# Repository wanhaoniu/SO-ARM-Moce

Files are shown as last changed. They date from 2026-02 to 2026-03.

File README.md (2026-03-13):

# MomoClaw 🤖
> An enhanced robotic arm based on SOARM101: higher payload, larger workspace, and the same control workflow and precision experience  

<p align="center">
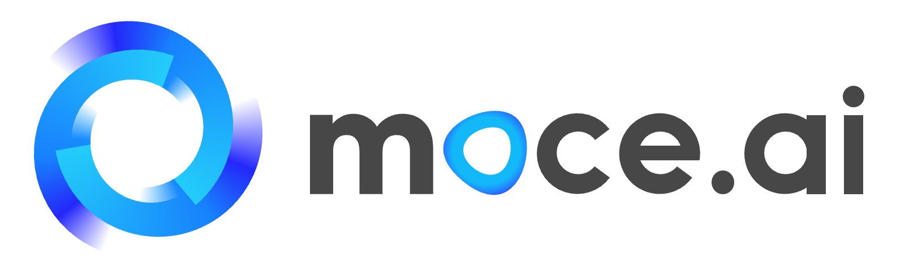
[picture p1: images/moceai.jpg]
MoceAI
  
  <span style="font-size: 24px; margin: 0 15px;">&times;</span>
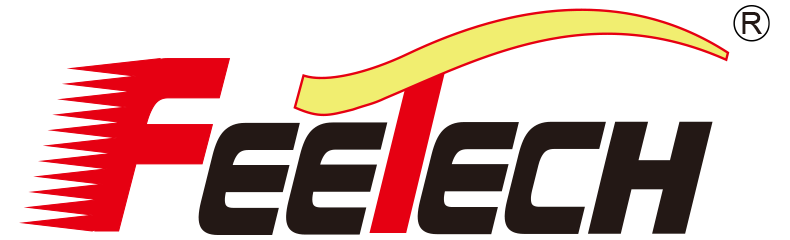
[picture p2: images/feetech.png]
Feetech
  
  <br>
  <em>Jointly Developed by MoceAI & Feetech</em>
</p>

> **Open-source plan: March 2026** (code and hardware materials will be released on the open-source date)

> **Homepage:** https://arm.moce.ai/

[English](README.md) | [中文](README_ZH.md)

MomoClaw Model Overview
<!-- TODO: Replace with your "model overview" image path, e.g. docs/media/overview.jpg -->

---

## 1. Project Overview
**MomoClaw** is our enhanced version built on top of **SOARM101**. While keeping the same **5-DOF architecture** and **Python + ROS control workflow**, we reinforce key joints with **metal reduction modules** to significantly improve payload capacity and structural stiffness, while also expanding workspace coverage.

### Development Motivation
We initially set out to create an **affordable, portable robotic arm** for our "mystery robot" project but found no existing products on the market that met our requirements. Therefore, **MoceAI**, with support from servo supplier **Feetech**, collaborated to develop and release this open-source robotic arm.

This project is designed for:
- Makers and open-source hardware developers (rapid secondary development and feature extensions)
- Education and lab teaching (ROS/kinematics/control/vision course support)
- Lightweight applications and prototyping (pick-and-place, interaction demos, etc.)

---

## 2. Appearance and Structure (Image Slots)
### 2.1 Model Overview
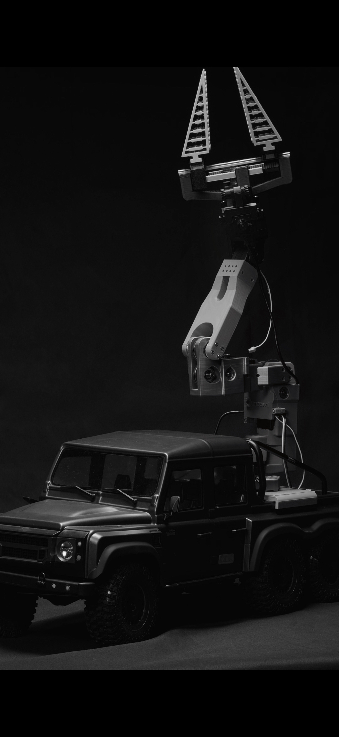
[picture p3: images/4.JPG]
Model Overview

<!-- TODO: Model overview image -->

### 2.2 SOARM101 vs MomoClaw Comparison
SOARM101 vs MomoClaw Comparison
<!-- TODO: Comparison image (recommended: payload/workspace/structural reinforcement points) -->

### 2.3 Core Module Close-up (Metal Reduction Module on Key Joint)
Key Module Close-up
<!-- TODO: Core close-up (recommended labels: key joint, reduction module, mounting position) -->

---

## 3. Key Upgrades (Compared to SOARM101)
- **Major payload boost**: Reinforced key joints with metal reduction modules, resulting in a significant payload increase (validated by experiments).
- **Larger workspace**: Based on public URDF simulation evaluation, workspace area increases by nearly 30%.
- **Higher stiffness and stability**: Reinforced structure provides stronger torsion and deformation resistance, improving overall system stability.
- **Same precision and control habits**: Repeatability remains 1 mm, and control stays Python + ROS, keeping the learning cost low.
- **More complete ecosystem**: Compatible with the upstream **LeRobot** ecosystem and extended with **Moce-specific ecosystem support**.

---

## 4. Core Metrics Comparison (SOARM101 vs MomoClaw)
> The following data is summarized from project comparison materials: payload values come from experiments, workspace-related values come from URDF simulation results.

| Metric | SOARM101 | MomoClaw | Change |
|---|---:|---:|---:|
| Rated max payload (kg) | 0.3 | 1.5 | **5x** increase |
| Limit payload (kg) | – | 2.0 | Higher payload headroom |
| Repeatability (mm) | 1.0 | 1.0 | Unchanged |
| Max horizontal reach Rmax (mm) | 380.6 | 433.1 | +13.8% |
| Max 3D reach Dmax (mm) | 447.2 | 516.2 | +15.4% |
| Max Z height (mm) | 428.7 | 502.9 | +17.3% |
| XY workspace area (m²) | 0.3255 | 0.4226 | +29.8% |
| Structural material | Standard 3D-printed structure | Reinforced 3D print + metal reduction modules | Higher stiffness |
| Key joint design | Conventional drive structure | Dual-joint metal reduction reinforced design | Torque amplification |
| Degrees of freedom (DOF) | 5 | 5 | Same architecture |
| End-effector support | Generic end-effector interface | Modular custom end-effector interface | Better extensibility |
| Control method | Python + ROS | Python + ROS | Same |
| Ecosystem support | LeRobot | LeRobot compatible + Moce ecosystem | More complete |
| Modular maintenance | Standard structure maintenance | Upgradable/replaceable key joints | Better maintainability |

---

## 5. Repository Contents (To Be Completed After Total Open Source)
> **Note: This repository will be completed on the open-source date in March 2026.**

Expected contents:
- `hardware/`: BOM, structural part list, machining/printing recommendations, assembly instructions
- `urdf/`: URDF files, mesh models, inertia/joint parameters
- `ros/`: ROS packages (launch, control, examples)
- `sdk/`: Python control interface, example scripts, API docs
- `docs/`: Calibration workflow, FAQ, development guide
- `examples/`: Trajectory following, teaching record, grasping demo (optional)

---

## 6. Quick Start
### 6.1 Environment
- Ubuntu 20.04/22.04 is recommended (master/slave serial + camera workflow is mainly Linux-oriented)
- Python 3.10 recommended (SDK minimum: Python 3.8)
- Real-arm mode needs one Leader + one Follower arm and valid serial ports (for example `/dev/ttyACM0`)
- Network ports: `6666/TCP` (control) and `6000/UDP` (camera stream, optional)

### 6.2 Install Dependencies
From repo root:
```bash
python3 -m venv .venv
source .venv/bin/activate
pip install -U pip
pip install -e ./sdk

# Master/Slave runtime
pip install draccus opencv-python PyQt5 lerobot

# Optional (simulation / 3D view)
pip install pybullet vtk
```

### 6.3 Start Leader-Follower Control (Real Hardware)
1. Start slave server on the follower-side device:
```bash
cd Software/Slave
python3 main.py
```
2. Start master client on your PC:
```bash
cd Software/Master
python3 main.py --ip <slave_ip> --port 6666 --leader-port /dev/ttyACM0 --leader-id black_arm_leader
```
3. Built-in CLI commands include:
`savepos`, `goto`, `record`, `play`, `home`, `quit`

Notes:
- If camera target IP or device path is different, update `TARGET_PC_IP` and `CAM1_PATH` in `Software/Slave/main.py`.
- Calibration files are under `Software/Master/calibration/...` and `Software/Slave/calibration/...`.
- Add `--no-cam` on master side if you only need arm control.

### 6.4 Start GUI (Optional)
```bash
cd Software/Master
python3 gui.py
```
Then configure IP/ports in the Settings page and click **Connect**.
If you run into issues, feel free to open an issue.

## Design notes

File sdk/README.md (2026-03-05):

# soarmmoce-sdk

Python SDK for SO-ARM-Moce.

## Install

```bash
pip install soarmmoce-sdk
```

For local development:

```bash
python -m venv .venv
source .venv/bin/activate
pip install -e .[dev]
```

## Quickstart

### 1) Use package default config

```python
from soarmmoce_sdk import Robot

robot = Robot()  # auto-loads resources/configs/soarm_moce.yaml
robot.connect()

state = robot.get_state()
print("q:", state.joint_state.q)
print("tcp xyz:", state.tcp_pose.xyz)

robot.home(duration=1.0)
robot.disconnect()
```

### 2) Use custom config file

```python
from soarmmoce_sdk import Robot

robot = Robot.from_config("/abs/path/to/soarm_moce.yaml")
robot.connect()
robot.move_pose([0.1, 0.0, 0.15], [0.0, 0.0, 0.0])
robot.disconnect()
```

## Optional Dependencies

```bash
pip install "soarmmoce-sdk[sim]"
pip install "soarmmoce-sdk[viz]"
pip install "soarmmoce-sdk[hardware]"
```

Notes:
- `sim` is currently the primary optional extra.
- `viz` and `hardware` are reserved extension groups for future features.

## Capability Notes

- `Robot.set_gripper(open_ratio, ...)` calls transport gripper support when available.
- If the active transport does not implement gripper control, SDK raises `CapabilityError`.
- `wait/timeout` are best-effort for transports that cannot yet report true motion completion.

## Examples

```bash
python examples/00_quickstart_connect.py
python examples/02_movepose_ik.py
python examples/02_movepose_ik.py --config /abs/path/to/soarm_moce.yaml
```

PyBullet demo:

```bash
pip install "soarmmoce-sdk[sim]"
python examples/03_sim.py
```

## Build & Package Check

```bash
python -m build
python -m zipfile -l dist/*.whl | grep "soarmmoce_sdk/resources/"
tar -tzf dist/*.tar.gz | grep "soarmmoce_sdk/resources/"
```

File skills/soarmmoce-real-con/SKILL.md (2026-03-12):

---
name: soarmmoce-real-con
description: 使用本技能通过本地 Python 脚本或本地 SDK 控制真实 soarmMoce 机械臂；适用于自然语言动作控制、连续小步笛卡尔移动、回零与状态查询。2/3 号关节按减速比 5.3/5.6 适配并运行在多圈模式，无夹爪舵机。
metadata:
  openclaw:
    emoji: "🤖"
    requires:
      bins: ["python3"]
---

# soarmmoce-real-con

## 功能概览

- 本技能用于直接控制本机串口连接的真实 `soarmMoce` follower arm。
- 代码结构分成两层：
  - `scripts/soarmmoce_sdk.py`：SDK 风格控制逻辑
  - `scripts/soarmmoce_state.py` / `scripts/soarmmoce_move.py`：命令行入口
- 当前 TCP 笛卡尔控制按 `5DOF position-only IK` 工作，只解末端位置 `x/y/z`，不再强行约束完整 6D 姿态。
- 对 `delta/xyz` 这类笛卡尔移动，默认锁住 `wrist_roll`，避免横移时为了凑位置把末端滚转甩开。
- 轨迹下发默认按时间频率连续插值，并使用平滑缓入缓出，避免单步跳变太大导致动作发卡。
- 2 号关节 `shoulder_lift` 与 3 号关节 `elbow_flex` 已分别按减速比 `5.3 / 5.6` 做换算，底层运行在多圈模式。
- 当前对 2/3 号多圈关节采用 `方案 A`：读状态时临时使用 `position mode`，发多圈步进命令时切回 `step mode`，这样才能既读到位置又继续用步进控制。
- 当前机械臂没有安装 6 号夹爪舵机，不要调用夹爪脚本或夹爪 API。

## 何时使用

- 用户说：`把机械臂抬高一点`、`往前一点`、`再来一点`、`回零`
- 用户要求状态查询：`当前机械臂在哪`
- 用户要执行多步动作，但不要求你生成正式项目代码

## 核心规则

1. 不要用 node 工具。
2. 脚本返回 JSON 仅供内部判断。
3. 默认最终回复只给用户自然语言。
4. 对普通空间动作，不要反问哪个关节、多少度。
5. 不要调用任何 gripper/open/close/set_gripper 相关命令。

## 推荐调用方式

### 1) 读取状态

```bash
python3 ~/.openclaw/skills/soarmmoce-real-con/scripts/soarmmoce_state.py
```

标定完多圈关节后，`state.joint_state.shoulder_lift / elbow_flex` 会返回用于运动和 IK 的关节角；如果你还想看多圈软件零点下的连续量，读 `state.multi_turn_state.relative_raw / joint_deg_from_home`。

### 1.1) 只读 IK 诊断

```bash
python3 ~/.openclaw/skills/soarmmoce-real-con/scripts/soarmmoce_diag_ik.py --dx 0.02 --frame base
```

### 1.2) 自动标定

运行前先把机械臂摆到你认定的 `home` 姿态。脚本会以当前姿态作为 `home` 参考位；单圈关节自动向正负两个方向寻限位，多圈关节也会自动向正负两个方向寻限位，但实际位置读取统一走 `position mode + 软件展开`。多圈结果不再依赖 `homing_offset`，而是写入 `home_wrapped_raw + min_relative_raw/max_relative_raw`。

```bash
python3 ~/.openclaw/skills/soarmmoce-real-con/scripts/soarmmoce_auto_calibrate.py
```

如果只想先生成 JSON，不回写寄存器：

```bash
python3 ~/.openclaw/skills/soarmmoce-real-con/scripts/soarmmoce_auto_calibrate.py --apply-registers false
```

### 1.3) 手动标定

运行方式对齐 `lerobot-calibrate` 的参数风格。脚本会在交互过程中让你手动把机械臂摆到目标 `home` 姿态；单圈和多圈关节都要再手动掰到整段活动范围。多圈关节在这里会把当前 `home` 姿态记成软件零点，再把整段范围记录成相对 `home` 的连续 raw。捕获 `home` 时脚本会实时打印 `HOME_RAW / WRAPPED / REF`，其中多圈关节的 `REF` 固定为 `0`；随后会再打印一次 `CAPTURED_RAW / HOME_ZERO`，需要你输入 `ok` 才继续。

```bash
python3 ~/.openclaw/skills/soarmmoce-real-con/scripts/soarmmoce_manual_calibrate.py \
  --robot.type=soarmmoce \
  --robot.port=/dev/ttyACM0 \
  --robot.id=soarmmoce
```

如果只想预览结果，不回写寄存器也不保存 JSON：

```bash
python3 ~/.openclaw/skills/soarmmoce-real-con/scripts/soarmmoce_manual_calibrate.py \
  --robot.type=soarmmoce \
  --robot.port=/dev/ttyACM0 \
  --robot.id=soarmmoce \
  --robot.apply_registers=false \
  --robot.save_json=false
```

### 1.4) 多圈极限位测试

这个脚本会读取当前多圈状态和标定 JSON，基于 `min_relative_raw/max_relative_raw` 规划相对 `home` 的目标位，并在范围看起来不可信时直接拒绝执行。

```bash
python3 ~/.openclaw/skills/soarmmoce-real-con/scripts/soarmmoce_test_calibrated_limits.py
```

确认计划没问题后，再执行真实运动：

```bash
python3 ~/.openclaw/skills/soarmmoce-real-con/scripts/soarmmoce_test_calibrated_limits.py --execute=true
```

### 2) 小步笛卡尔移动

```bash
python3 ~/.openclaw/skills/soarmmoce-real-con/scripts/soarmmoce_move.py delta --dz 0.01 --frame base
```

需要排查多圈关节执行误差时，给运动命令加 `--trace`：

```bash
python3 ~/.openclaw/skills/soarmmoce-real-con/scripts/soarmmoce_move.py delta --dy 0.05 --frame base --duration 2.0 --trace
```

### 3) 绝对 XYZ 移动

```bash
python3 ~/.openclaw/skills/soarmmoce-real-con/scripts/soarmmoce_move.py xyz --x 0.22 --y 0.00 --z 0.18
```

### 4) 关节级低层修正

```bash
python3 ~/.openclaw/skills/soarmmoce-real-con/scripts/soarmmoce_move.py joint --joint wrist_roll --delta-deg 5
```

### 5) 回零

```bash
python3 ~/.openclaw/skills/soarmmoce-real-con/scripts/soarmmoce_move.py home
```

## SDK 直接调用

```python
from soarmmoce_sdk import SoArmMoceController

arm = SoArmMoceController()
arm.move_delta(dz=0.01, frame="base")
print(arm.get_state())
```

运行临时脚本时建议显式带上：

```bash
PYTHONPATH=~/.openclaw/skills/soarmmoce-real-con/scripts python3 /tmp/soarmmoce_sequence.py
```

## 可用 API

- `SoArmMoceController().read()`
- `SoArmMoceController().get_state()`
- `SoArmMoceController().move_delta(...)`
- `SoArmMoceController().move_to(...)`
- `SoArmMoceController().move_joint(...)`
- `SoArmMoceController().move_joints(...)`
- `SoArmMoceController().home()`
- `SoArmMoceController().stop()`

以下接口会直接报错，因为当前硬件没有夹爪舵机：

- `SoArmMoceController().set_gripper(...)`
- `SoArmMoceController().open_gripper()`
- `SoArmMoceController().close_gripper()`

## 环境变量

- `SOARMMOCE_PORT`：串口，默认 `/dev/ttyACM0`
- `SOARMMOCE_ROBOT_ID`：标定 ID，默认优先 `soarmmoce`，找不到再回退 `follower_moce`
- `SOARMMOCE_CALIB_DIR`：标定目录
- `SOARMMOCE_URDF_PATH`：URDF 路径，默认优先使用 `sdk/src/soarmmoce_sdk/resources/urdf/soarmoce_urdf.urdf`
- `SOARMMOCE_TARGET_FRAME`：末端 frame，默认 `wrist_roll`（按当前 5DOF 链截断）
- `SOARMMOCE_HOME_JOINTS_JSON`：覆盖 home 目标关节
- `SOARMMOCE_JOINT_SCALE_JSON`：覆盖关节减速比/方向，默认 `{"shoulder_pan":1.0,"shoulder_lift":5.3,"elbow_flex":5.6,"wrist_flex":1.0,"wrist_roll":1.0}`
- `SOARMMOCE_LINEAR_STEP_M`：笛卡尔插值步长，默认 `0.01`
- `SOARMMOCE_JOINT_STEP_DEG`：关节插值步长，默认 `5.0`
- `SOARMMOCE_CARTESIAN_UPDATE_HZ`：笛卡尔轨迹下发频率，默认 `20.0`
- `SOARMMOCE_JOINT_UPDATE_HZ`：关节轨迹下发频率，默认 `25.0`
- `SOARMMOCE_MAX_EE_POS_ERR_M`：笛卡尔动作最终位置误差容忍，默认 `0.01`
- `SOARMMOCE_IK_TARGET_TOL_M`：5DOF IK 收敛阈值，默认 `0.001`
- `SOARMMOCE_IK_MAX_ITERS`：5DOF IK 最大迭代次数，默认 `200`
- `SOARMMOCE_IK_DAMPING`：5DOF IK 阻尼系数，默认 `0.05`
- `SOARMMOCE_IK_STEP_SCALE`：5DOF IK 每轮步进缩放，默认 `0.8`
- `SOARMMOCE_IK_JOINT_STEP_DEG`：5DOF IK 单轮单关节最大步长，默认 `8.0`
- `SOARMMOCE_IK_SEED_BIAS`：5DOF IK 保持当前姿态的偏置强度，默认 `0.02`
- `SOARMMOCE_ARM_P_COEFFICIENT`：单圈关节 P 参数，默认 `16`
- `SOARMMOCE_ARM_D_COEFFICIENT`：单圈关节 D 参数，默认 `8`

## 执行策略

默认优先级：
1. `soarmmoce_state.py`
2. `soarmmoce_move.py delta`
3. `soarmmoce_move.py xyz`
4. `soarmmoce_move.py home`
5. SDK 临时脚本
6. `joint` / `joints` 仅作低层兜底

对 `上/下/左/右` 默认使用 `frame="base"`。
只有用户明确要求沿末端当前方向前进/后退时，才优先使用 `frame="tool"`。

串口相关脚本不要并行运行；同一时刻只保留一个 `state/move/diag` 进程，否则容易出现假性的缺电机 ID 或端口占用。

自动标定脚本同样不要和其它串口脚本并行运行。它的限位判定优先看 `Present_Velocity + Moving`，`Present_Current` 只作为兜底异常保护。

## 参考文件

- `skills/soarmmoce-real-con/scripts/soarmmoce_sdk.py`
- `skills/soarmmoce-real-con/scripts/soarmmoce_auto_calibrate.py`
- `skills/soarmmoce-real-con/scripts/soarmmoce_manual_calibrate.py`
- `skills/soarmmoce-real-con/scripts/soarmmoce_state.py`
- `skills/soarmmoce-real-con/scripts/soarmmoce_diag_ik.py`
- `skills/soarmmoce-real-con/scripts/soarmmoce_move.py`
- `skills/soarmmoce-real-con/agents/openai.yaml`

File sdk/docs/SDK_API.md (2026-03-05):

# SoarmMoce SDK API Reference

Package:
- PyPI: `soarmmoce-sdk`
- Import: `soarmmoce_sdk`

Main entry:
- `from soarmmoce_sdk import Robot`

## Quick Start

```python
from soarmmoce_sdk import Robot

robot = Robot()  # load built-in default config
robot.connect()
state = robot.get_state()
print(state.connected, state.joint_state.q, state.tcp_pose.xyz)
robot.disconnect()
```

## Data Models

`JointState`
- `q: np.ndarray`
- `dq: Optional[np.ndarray]`
- `tau: Optional[np.ndarray]`

`Pose`
- `xyz: np.ndarray` (meters)
- `rpy: np.ndarray` (radians)

`GripperState`
- `available: bool`
- `open_ratio: Optional[float]` (`0.0` closed, `1.0` open)
- `moving: Optional[bool]`

`PermissionState`
- `allow_motion: bool`
- `allow_gripper: bool`
- `allow_home: bool`
- `allow_stop: bool`

`RobotState`
- `connected: bool`
- `joint_state: JointState`
- `tcp_pose: Pose`
- `gripper_state: Optional[GripperState]`
- `permissions: Optional[PermissionState]`
- `timestamp: Optional[float]` (unix seconds)

## Error Types

- `SoarmMoceError` (base)
- `ConnectionError`
- `ProtocolError`
- `TimeoutError`
- `IKError`
- `LimitError`
- `CapabilityError`
- `PermissionError`

## Robot API

### Construction

```python
Robot(
    config_path: Optional[str] = None,
    transport: Optional[TransportBase] = None,
    urdf_path: Optional[str] = None,
    base_link: Optional[str] = None,
    end_link: Optional[str] = None,
)
```

Classmethod:

```python
Robot.from_config(path: str, ...)
```

Properties:
- `connected -> bool`
- `permissions -> PermissionState`

Permission mutation:

```python
robot.set_permissions(
    allow_motion: Optional[bool] = None,
    allow_gripper: Optional[bool] = None,
    allow_home: Optional[bool] = None,
    allow_stop: Optional[bool] = None,
) -> PermissionState
```

### Connection

- `connect() -> None`
- `disconnect() -> None`

### State

- `get_joint_state() -> JointState`
- `get_end_effector_pose(q: Optional[Sequence[float]] = None) -> Pose`
- `get_gripper_state() -> GripperState`
- `get_state() -> RobotState`

### Motion

```python
move_joints(
    q: Sequence[float],
    duration: float = 2.0,
    wait: bool = True,
    timeout: Optional[float] = None,
    speed: Optional[float] = None,
    accel: Optional[float] = None,
) -> None
```

```python
move_pose(
    xyz: Sequence[float],
    rpy: Sequence[float],
    q0: Optional[Sequence[float]] = None,
    seed_policy: str = "current",
    duration: float = 2.0,
    wait: bool = True,
    timeout: Optional[float] = None,
    speed: Optional[float] = None,
    accel: Optional[float] = None,
) -> np.ndarray
```

```python
move_tcp(
    x: float,
    y: float,
    z: float,
    rpy: Optional[Sequence[float]] = None,
    frame: str = "base",  # "base" absolute target, "tool" local offset
    duration: float = 2.0,
    wait: bool = True,
    timeout: Optional[float] = None,
) -> np.ndarray
```

```python
rotate_joint(
    joint: Union[int, str],
    delta_deg: Optional[float] = None,
    target_deg: Optional[float] = None,  # exactly one of delta_deg/target_deg
    duration: float = 1.0,
    wait: bool = True,
    timeout: Optional[float] = None,
    speed: Optional[float] = None,
    accel: Optional[float] = None,
) -> np.ndarray
```

### High-Level

- `home(duration: float = 2.0, wait: bool = True, timeout: Optional[float] = None) -> np.ndarray`
- `set_gripper(open_ratio: float, wait: bool = True, timeout: Optional[float] = None) -> None`
- `stop() -> None`
- `wait_until_stopped(timeout: Optional[float] = None) -> None`

## Wait/Timeout Semantics

- `wait=True` means the API calls `wait_until_stopped`.
- Some transports cannot confirm physical completion; they use best-effort behavior.
- `TimeoutError` is raised if wait times out.

## Configuration Keys (default config)

Core:
- `transport.type`: `mock` | `tcp` | `serial`
- `urdf.path`: supports `pkg://...`
- `protocol.*`: tcp protocol options

Permissions:
- `permissions.allow_motion`
- `permissions.allow_gripper`
- `permissions.allow_home`
- `permissions.allow_stop`

Example:

```yaml
transport:
  type: mock

permissions:
  allow_motion: true
  allow_gripper: true
  allow_home: true
  allow_stop: true
```

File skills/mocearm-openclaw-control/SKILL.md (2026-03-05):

---
name: mocearm-openclaw-control
description: Use this skill when implementing or running OpenClaw function-calling for SO-ARM-MoceArm, including move_robot_arm/get_robot_state/get_camera_frame/stop_robot/set_gripper/rotate_joint/scan_for_object tools, JSON schemas, and safe prompt behavior for simulation-first robot control.
---

# MoceArm OpenClaw Control

## Role

你叫 Momo，是一个活泼、专业且极其可靠的智能机械臂控制助手。

你的职责是协助主人（说话者）完成 SO-ARM-MoceArm 的日常开发、仿真测试与实机操控。

## When To Use

Use this skill when the user asks for any of the following:

- Define or update OpenClaw tool-calling / function-calling interfaces for the robot.
- Execute robot actions through `move_robot_arm`, `get_robot_state`, `get_camera_frame`, `set_gripper`, `rotate_joint`, `scan_for_object`, or `stop_robot`.
- Connect speech/NLU output to executable robot skills.
- Build or validate JSON schemas for tool calls.

Do not use this skill for unrelated UI styling or non-robot general coding tasks.

## Capability Contract

The runtime exposes these tools in the HMI dispatcher (and in standalone mode can be mirrored via [`scripts/mocearm_tools.py`](./scripts/mocearm_tools.py)):

- `move_robot_arm(x, y, z, frame="base", duration=2.0, wait=true)`
- `get_robot_state()`
- `get_camera_frame(source="eye_in_hand", width=960, height=720, format="jpg", return_mode="path")`
- `set_gripper(open_ratio, wait=true)` where `open_ratio` in `[0,1]`
- `rotate_joint(joint_name, delta_deg?, target_deg?, wait=true)`
- `scan_for_object(object_name, sweep_range_deg=120, step_deg=15, source="eye_in_hand", width=960, height=720)`
- `run_skill(name, params)`
- `stop_robot()`

Conventions:

- Cartesian unit is meters (`m`).
- Default camera return mode is file path (`return_mode="path"`).
- `scan_for_object` currently uses a red-color detector optimized for "红苹果 / red apple" style targets.
- The backend is simulation-first (PyBullet) unless adapted by project code.

Canonical schema copy is in [`references/tool_schemas.json`](./references/tool_schemas.json).

## Interaction Guidelines

1. 性格：保持积极、干脆、专业。回答简洁，不写长篇说明。
2. 严谨：执行空间移动前可做一次简短坐标复述，避免误操作。
3. 未知处理：当坐标意图不清晰、超出工具能力或执行失败时，必须明确说明，不得编造结果。
4. 感知优先：当用户问机械臂状态或环境信息时，优先调用 `get_robot_state` / `get_camera_frame`，抓取类任务优先 `scan_for_object`。
5. 紧急处理：遇到“停止”“急停”“危险”等信号，立即优先调用 `stop_robot`。

## Safety Rules

- Never claim motion success without tool return data.
- Reject or ask to clarify ambiguous Cartesian targets.
- Keep commands inside configured safety workspace.
- For real hardware migration, add hardware interlocks before enabling direct execution.

## Execution Workflow

1. Parse user intent from text/STT result.
2. Choose the minimal safe tool call.
3. For grasp-like goals, prefer `scan_for_object -> move_robot_arm -> set_gripper`.
4. Execute tool(s) and inspect returned fields (`ok`, `within_tolerance`, `found`, `confidence`).
5. Report concise factual results (target, actual pose/error, frame path/state).
6. If risk or failure appears, call `stop_robot` and report remediation.

## Start Behavior

When explicitly asked to start this assistant persona, greet once and wait for the next command.

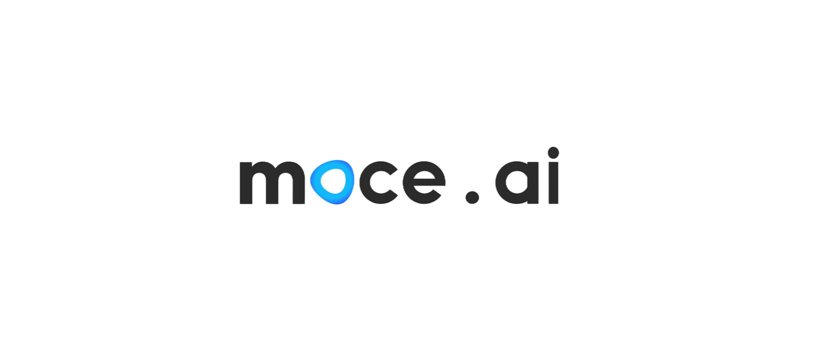
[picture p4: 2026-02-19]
Software/Master/Picture/moceai.png

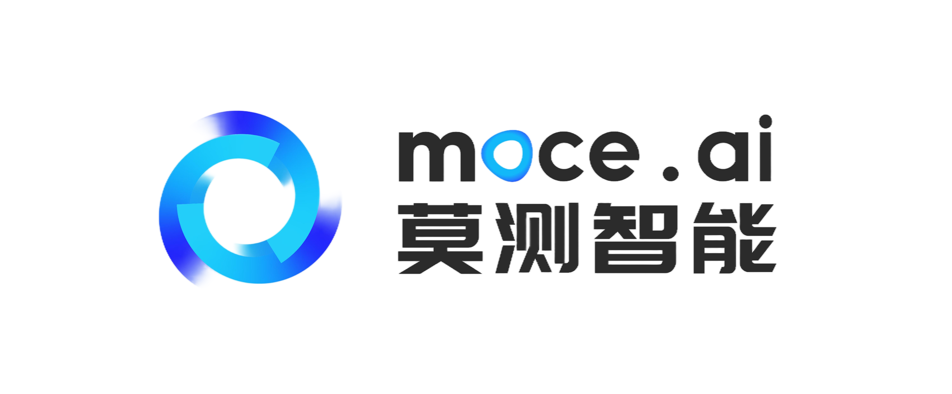
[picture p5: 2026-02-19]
Software/Master/Picture/组合.jpg

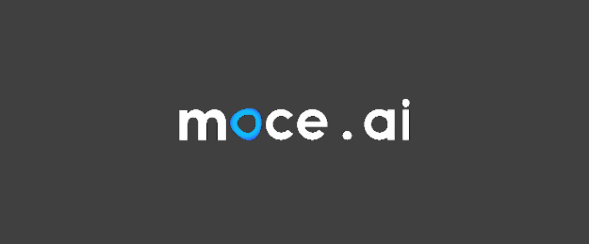
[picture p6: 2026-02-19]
Software/Master/Picture/moceai_Drak.jpg

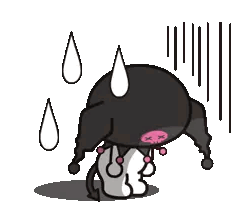
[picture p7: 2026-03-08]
GIF/sad.gif

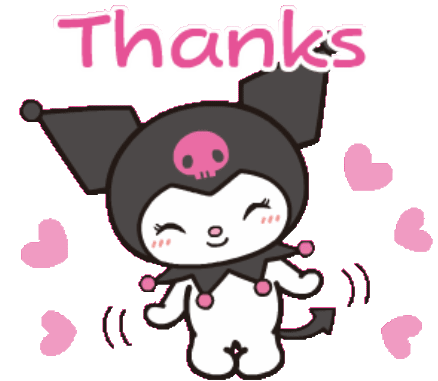
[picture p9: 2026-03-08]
GIF/thanks.gif

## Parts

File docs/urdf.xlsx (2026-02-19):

关节顺序 | 关节名称 (Joint Name) | 父连杆 (Parent Link) | 子连杆 (Child Link) | 运动类型 | 旋转轴 | 软件限位 (弧度) | 对应角度 (约)
1 | shoulder_pan | base_link | shoulder_link | 旋转 (Revolute) | Z | ±1.91986 | ±110°
2 | shoulder_lift | shoulder_link | upper_arm_link | 旋转 (Revolute) | Z | ±1.74533 | ±100°
3 | elbow_flex | upper_arm_link | lower_arm_link | 旋转 (Revolute) | Z | ±1.69 | ±97°
4 | wrist_flex | lower_arm_link | wrist_link | 旋转 (Revolute) | Z | ±1.65806 | ±95°
5 | wrist_roll | wrist_link | gripper_link | 旋转 (Revolute) | Z | -0.9647887324 | -157° / +162°
6 | gripper | gripper_link | moving_jaw...link | 旋转 (Revolute) | Z | -0.09770114943 | -10° / +100°

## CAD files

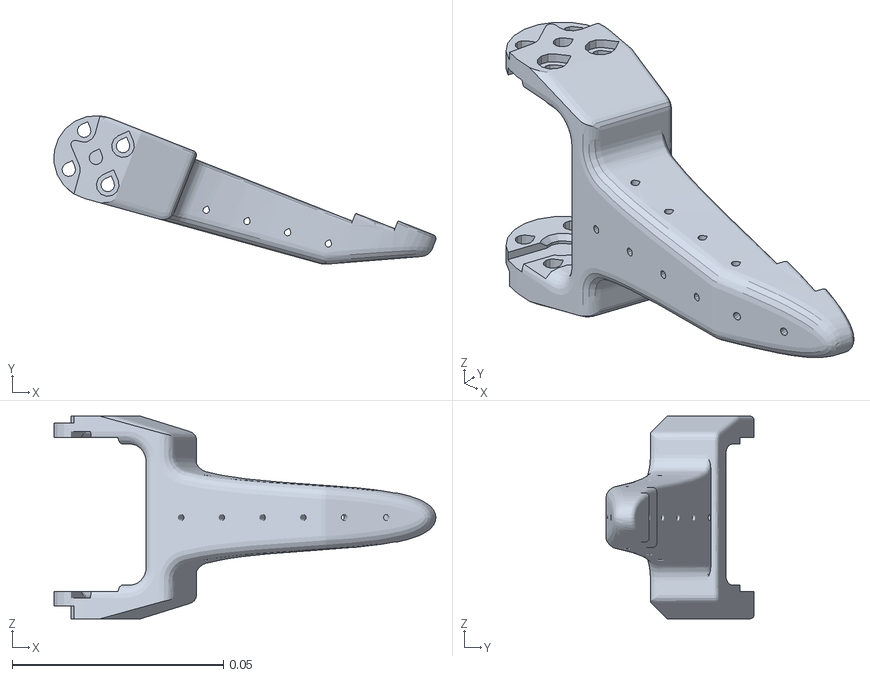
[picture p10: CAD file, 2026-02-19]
sdk/src/soarmmoce_sdk/resources/meshes/gripper.STL
0.0904 x 0.0352 x 0.048

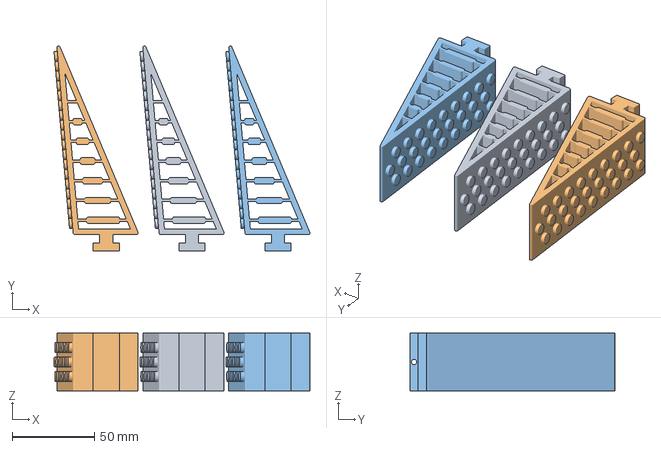
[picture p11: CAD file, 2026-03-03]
step/3dprint/soarm_moce_jaw_finger_3jaw_3dprint_TPU.3mf
155.7 x 124.7 x 35.0 mm
jaw_finger_3jaw_ee_soarm_moce.STEP x 3

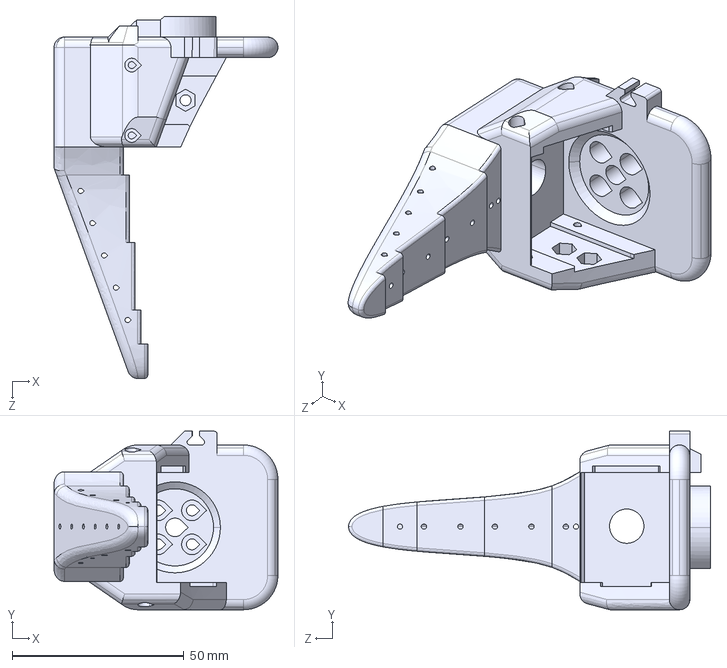
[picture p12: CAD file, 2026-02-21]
step/Wrist_Roll_Follower_SO101.STEP
65.2 x 52.0 x 105.4 mm

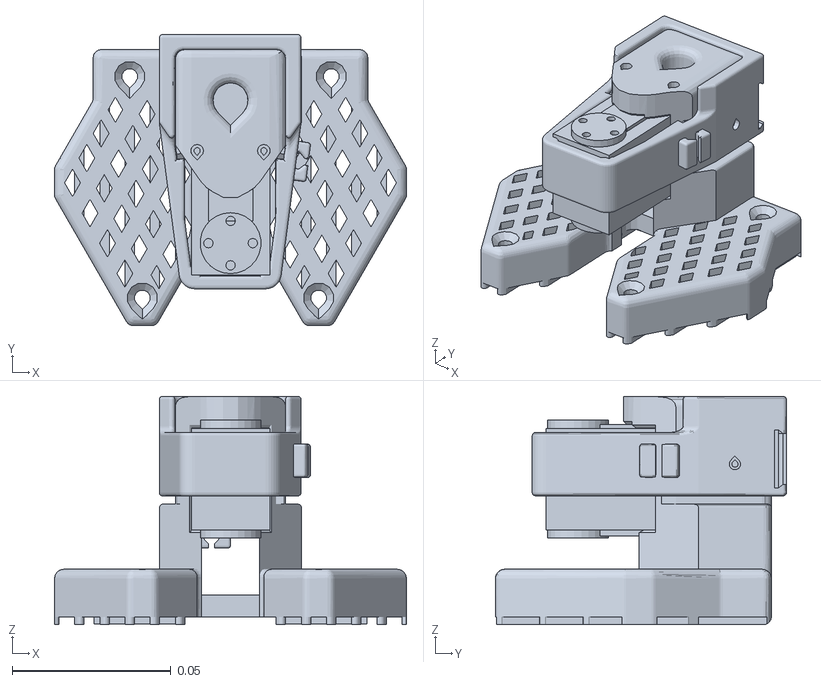
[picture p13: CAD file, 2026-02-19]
sdk/src/soarmmoce_sdk/resources/meshes/base.STL
0.111 x 0.0918 x 0.072

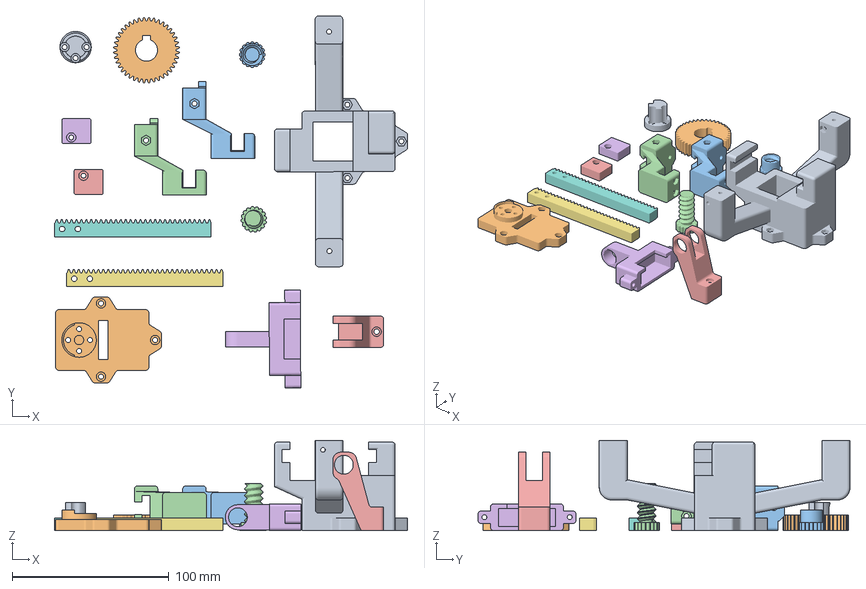
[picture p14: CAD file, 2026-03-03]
step/3dprint/soarm_moce_ee_2jaw_linear_3dprint_PLA.3mf
225.4 x 237.4 x 57.5 mm
drive_shaft_2jaw_linear_soarm_moce.STEP
gear_1m_40t_2jaw_linear_soarm_moce.STEP
jaw_carrier_2jaw_linear_soarm_moce.STEP x 2
linear_slide_stop_2jaw_linear_l_soarm_moce.STEP
linear_slide_stop_2jaw_linear_r_soarm_moce.STEP
rack_2jaw_linear_soarm_moce.STEP x 2
servo_base_2jaw_linear_soarm_moce.STEP
connecting_backplate_ee_soarm_moce.STEP
camera_mount_nut_soarm_moce.STEP
camera_mount_screw_soarm_moce.STEP
coupling_part_servo_camera_ee_soarm_moce.STEP
camera_base_3jaw_ee_soarm_moce.STEP

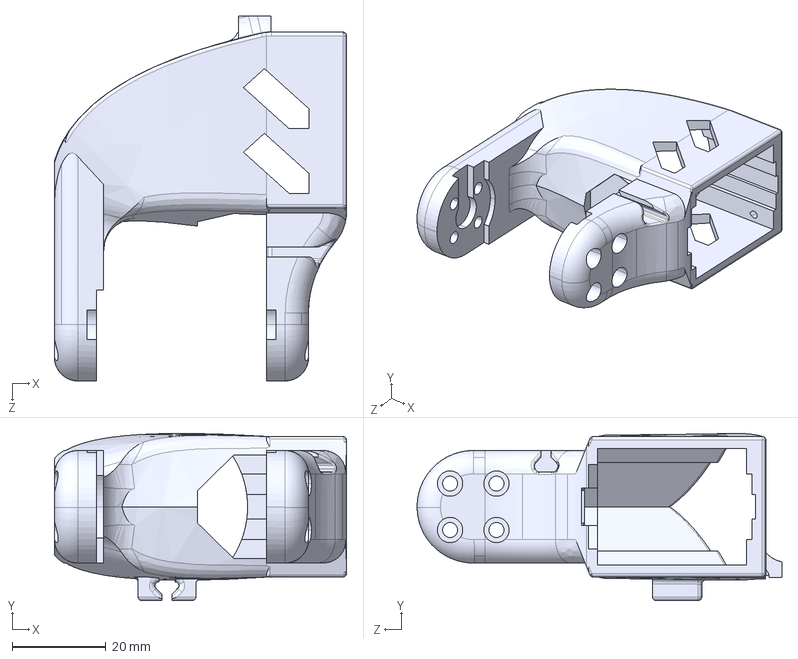
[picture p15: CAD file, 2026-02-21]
step/Wrist_Roll_Pitch_SO101.STEP
62.3 x 35.6 x 77.8 mm

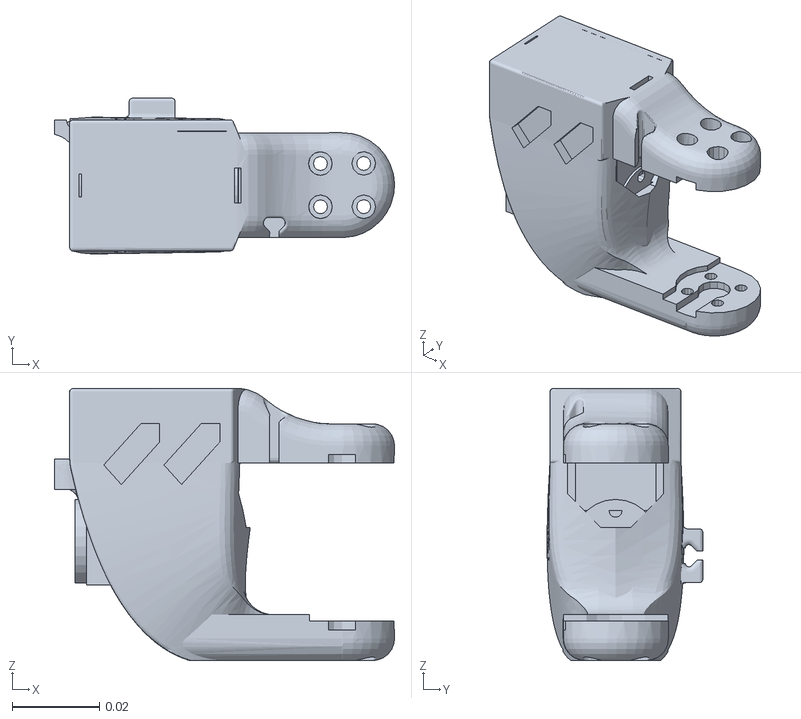
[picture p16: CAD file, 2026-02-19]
sdk/src/soarmmoce_sdk/resources/meshes/wrist.STL
0.0779 x 0.0357 x 0.0623

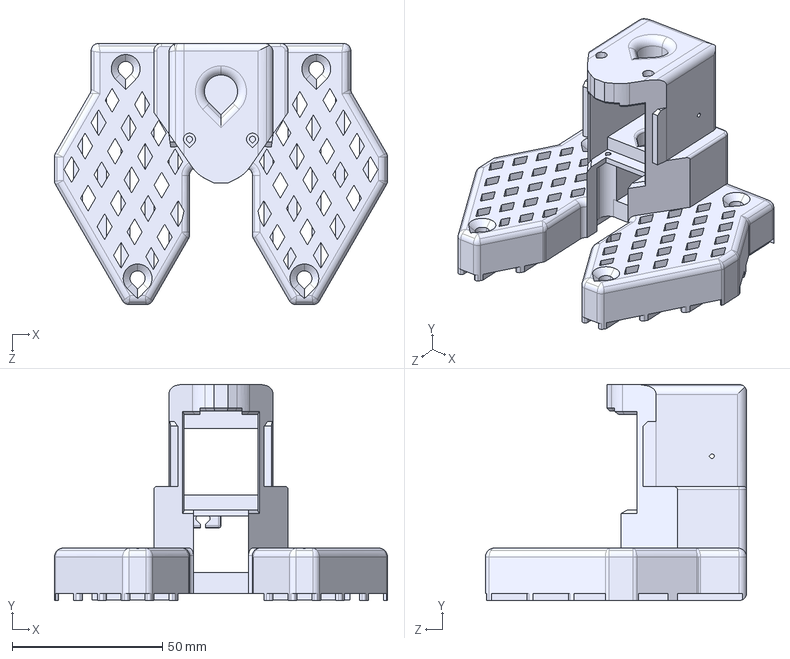
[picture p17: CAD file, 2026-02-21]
step/base_so101.STEP
110.9 x 72.0 x 87.0 mm

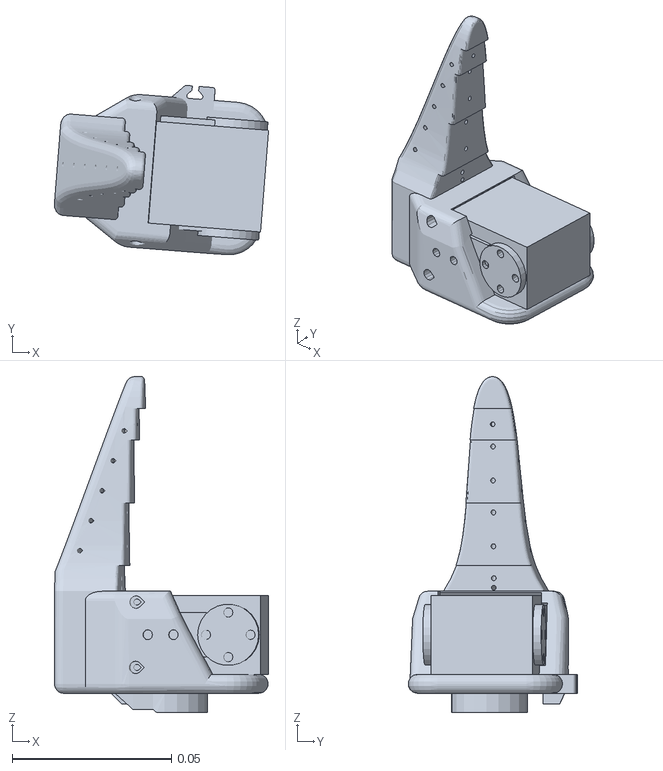
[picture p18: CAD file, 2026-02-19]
sdk/src/soarmmoce_sdk/resources/meshes/wrist_roll.STL
0.0672 x 0.0531 x 0.105

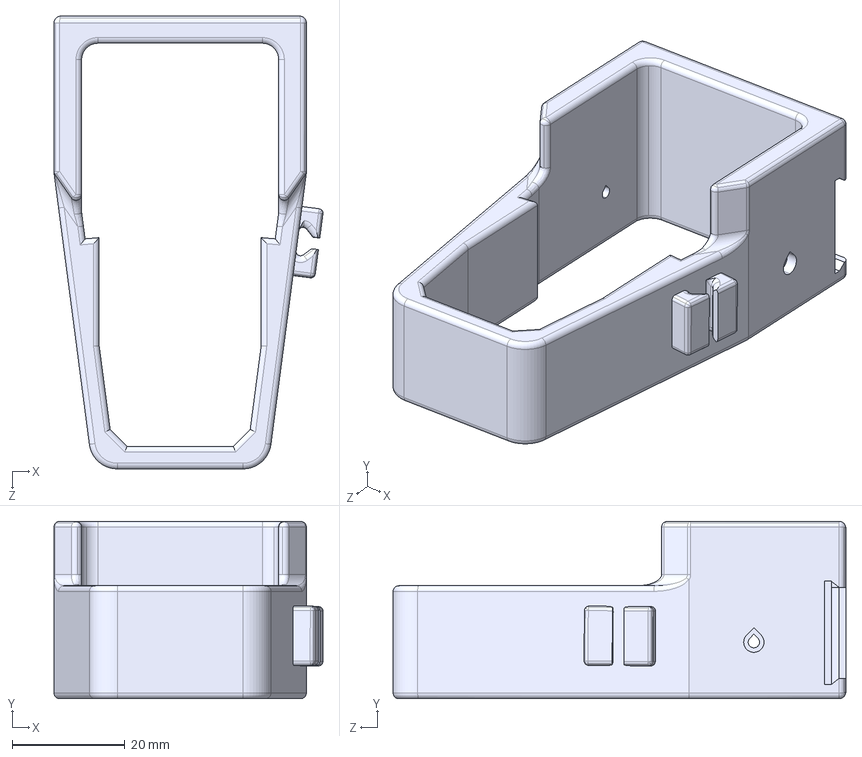
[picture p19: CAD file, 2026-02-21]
step/Base_motor_holder_SO101.STEP
47.6 x 31.4 x 80.2 mm

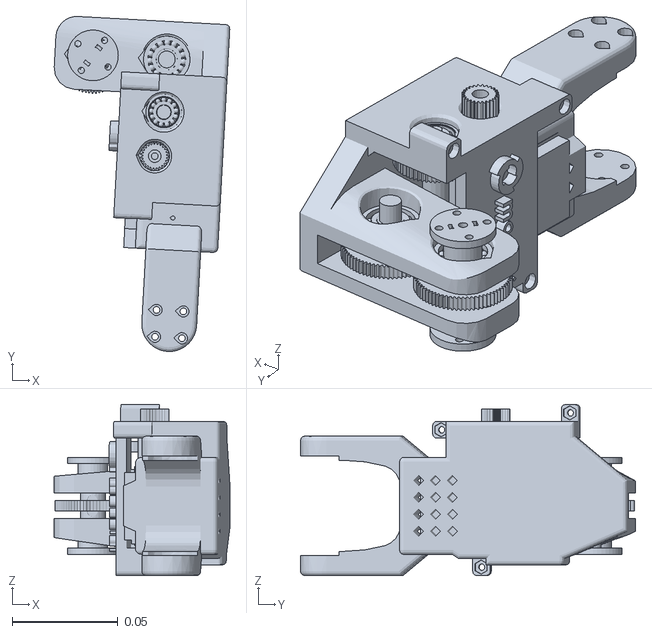
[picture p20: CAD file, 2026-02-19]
sdk/src/soarmmoce_sdk/resources/meshes/shoulder_lift.STL
0.0831 x 0.159 x 0.081

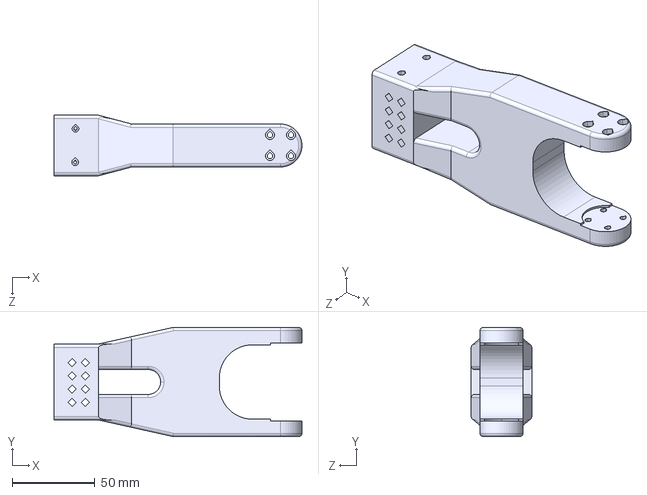
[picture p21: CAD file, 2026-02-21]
step/forearm_soarm_moce.STEP
150.0 x 66.0 x 36.6 mm

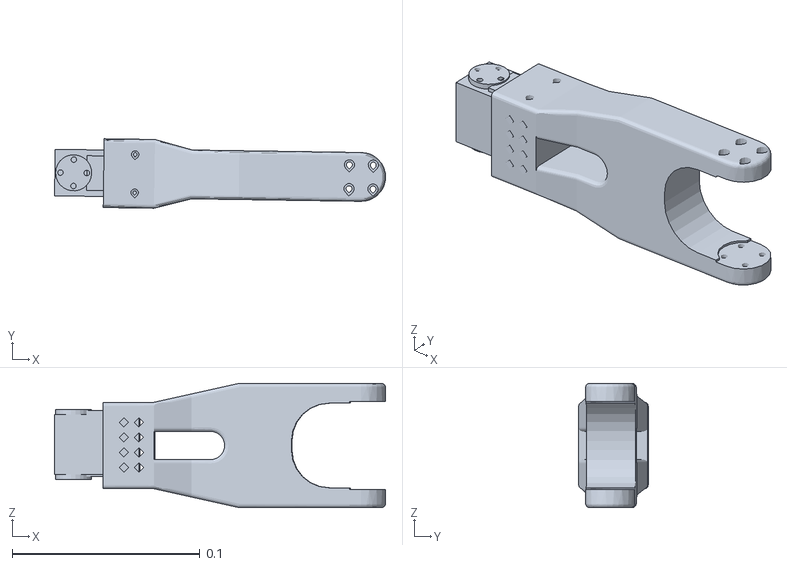
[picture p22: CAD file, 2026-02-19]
sdk/src/soarmmoce_sdk/resources/meshes/elbow.STL
0.176 x 0.037 x 0.066

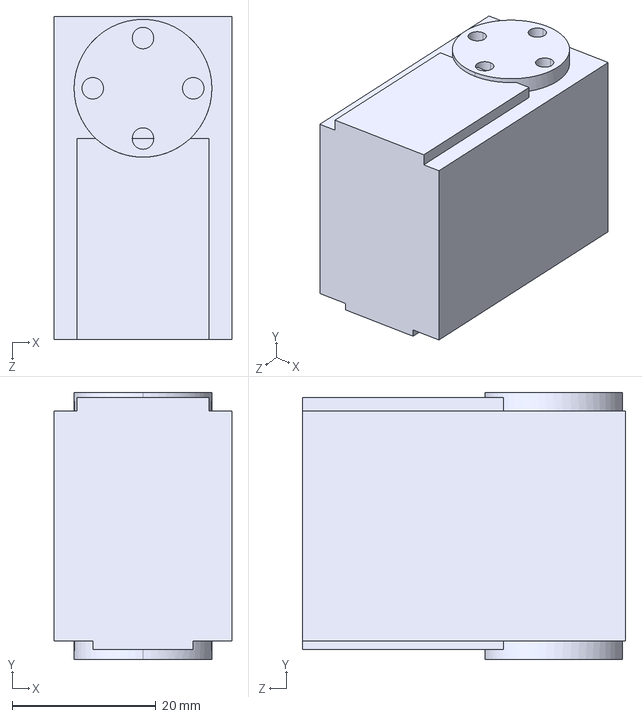
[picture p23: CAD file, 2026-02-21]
step/servo_soarm_moce.STEP
24.8 x 37.2 x 45.0 mm

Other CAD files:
sdk/src/soarmmoce_sdk/resources/meshes/shoulder.STL
step/moving_jaw_so101.STEP
sdk/src/soarmmoce_sdk/resources/apple/Apple.CATPart

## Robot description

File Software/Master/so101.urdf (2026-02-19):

<?xml version="1.0" encoding="utf-8"?>
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
<robot name="so101_new_calib">

  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
  <link name="base_link">
    <inertial>
      <origin xyz="0.0137179 -5.19711e-05 0.0334843" rpy="0 0 0"/>
      <mass value="0.147"/>
      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
    </inertial>
    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
  </link>

  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
  <link name="shoulder_link">
    <inertial>
      <origin xyz="-0.0307604 -1.66727e-05 -0.0252713" rpy="0 0 0"/>
      <mass value="0.100006"/>
      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
    </inertial>
    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
  </link>

  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
  <link name="upper_arm_link">
    <inertial>
      <origin xyz="-0.0898471 -0.00838224 0.0184089" rpy="0 0 0"/>
      <mass value="0.103"/>
      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
    </inertial>
    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
  </link>

  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
  <link name="lower_arm_link">
    <inertial>
      <origin xyz="-0.0980701 0.00324376 0.0182831" rpy="0 0 0"/>
      <mass value="0.104"/>
      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
    </inertial>
    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
  </link>

  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
  <link name="wrist_link">
    <inertial>
      <origin xyz="-0.000103312 -0.0386143 0.0281156" rpy="0 0 0"/>
      <mass value="0.079"/>
      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
    </inertial>
    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
  </link>

  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
  <link name="gripper_link">
    <inertial>
      <origin xyz="0.000213627 0.000245138 -0.025187" rpy="0 0 0"/>
      <mass value="0.087"/>
      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
    </inertial>
    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
  </link>

  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
  <link name="gripper_frame_link">
    <origin xyz="0 0 0" rpy="0 -0 0"/>
    <inertial>
      <origin xyz="0 0 0" rpy="0 0 0"/>
      <mass value="1e-9"/>
      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
    </inertial>
  </link>

  <joint name="gripper_frame_joint" type="fixed">
    <origin xyz="-0.0079 -0.000218121 -0.0981274" rpy="0 3.14159 0"/>
    <parent link="gripper_link"/>
    <child link="gripper_frame_link"/>
    <axis xyz="0 0 0"/>
  </joint>

  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
  <link name="moving_jaw_so101_v1_link">
    <inertial>
      <origin xyz="-0.00157495 -0.0300244 0.0192755" rpy="0 0 0"/>
      <mass value="0.012"/>
      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
    </inertial>
    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
  </link>

  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
  <joint name="gripper" type="revolute">
    <origin xyz="0.0202 0.0188 -0.0234" rpy="1.5708 -5.24284e-08 -1.41553e-15"/>
    <parent link="gripper_link"/>
    <child link="moving_jaw_so101_v1_link"/>
    <axis xyz="0 0 1"/>
    <limit effort="10" velocity="10" lower="-0.174533" upper="1.74533"/>
  </joint>

  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
  <joint name="wrist_roll" type="revolute">
    <origin xyz="5.55112e-17 -0.0611 0.0181" rpy="1.5708 0.0486795 3.14159"/>
    <parent link="wrist_link"/>
    <child link="gripper_link"/>
    <axis xyz="0 0 1"/>
    <limit effort="10" velocity="10" lower="-2.74385" upper="2.84121"/>
  </joint>

  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
  <joint name="wrist_flex" type="revolute">
    <origin xyz="-0.1349 0.0052 3.62355e-17" rpy="4.02456e-15 8.67362e-16 -1.5708"/>
    <parent link="lower_arm_link"/>
    <child link="wrist_link"/>
    <axis xyz="0 0 1"/>
    <limit effort="10" velocity="10" lower="-1.65806" upper="1.65806"/>
  </joint>

  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
  <joint name="elbow_flex" type="revolute">
    <origin xyz="-0.11257 -0.028 1.73763e-16" rpy="-3.63608e-16 8.74301e-16 1.5708"/>
    <parent link="upper_arm_link"/>
    <child link="lower_arm_link"/>
    <axis xyz="0 0 1"/>
    <limit effort="10" velocity="10" lower="-1.69" upper="1.69"/>
  </joint>

  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
  <joint name="shoulder_lift" type="revolute">
    <origin xyz="-0.0303992 -0.0182778 -0.0542" rpy="-1.5708 -1.5708 0"/>
    <parent link="shoulder_link"/>
    <child link="upper_arm_link"/>
    <axis xyz="0 0 1"/>
    <limit effort="10" velocity="10" lower="-1.74533" upper="1.74533"/>
  </joint>

  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
  <joint name="shoulder_pan" type="revolute">
    <origin xyz="0.0388353 -8.97657e-09 0.0624" rpy="3.14159 4.18253e-17 -3.14159"/>
    <parent link="base_link"/>
    <child link="shoulder_link"/>
    <axis xyz="0 0 1"/>
    <limit effort="10" velocity="10" lower="-1.91986" upper="1.91986"/>
  </joint>

  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 

</robot>

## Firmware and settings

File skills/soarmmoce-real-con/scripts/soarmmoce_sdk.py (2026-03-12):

#!/usr/bin/env python3
"""SDK-style control module for the local soarmMoce follower arm."""

from __future__ import annotations

import contextlib
import io
import json
import math
import os
import threading
import time
import types
from dataclasses import dataclass
from pathlib import Path
from typing import Any, Dict, Optional

import draccus
import kinpy as kp
import numpy as np
from lerobot.motors import Motor, MotorCalibration, MotorNormMode
from lerobot.motors.feetech import FeetechMotorsBus, OperatingMode


REPO_ROOT = Path(__file__).resolve().parents[3]
SKILL_ROOT = Path(__file__).resolve().parents[1]
JOINTS = [
    "shoulder_pan",
    "shoulder_lift",
    "elbow_flex",
    "wrist_flex",
    "wrist_roll",
]
ARM_JOINTS = list(JOINTS)
MULTI_TURN_JOINTS = ("shoulder_lift", "elbow_flex")
LOCKED_CARTESIAN_JOINTS = ("wrist_roll",)
MULTI_TURN_RAW_RANGE = 900000
RAW_COUNTS_PER_REV = 4096.0
HALF_RAW_COUNTS_PER_REV = RAW_COUNTS_PER_REV / 2.0
DEFAULT_TARGET_FRAME = "wrist_roll"
DEFAULT_HOME_JOINTS = {
    "shoulder_pan": -8.923076923076923,
    "shoulder_lift": -9.31868131868132,
    "elbow_flex": 8.483516483516484,
    "wrist_flex": -3.6043956043956045,
    "wrist_roll": -0.17582417582417584,
}
DEFAULT_JOINT_SCALES = {
    "shoulder_pan": 1.0,
    "shoulder_lift": 5.3,
    "elbow_flex": 5.6,
    "wrist_flex": 1.0,
    "wrist_roll": 1.0,
}
MULTI_TURN_READ_MODE = "read"
MULTI_TURN_STEP_MODE = "step"
__all__ = [
    "ARM_JOINTS",
    "JOINTS",
    "HardwareError",
    "IKError",
    "SoArmMoceConfig",
    "SoArmMoceController",
    "ValidationError",
    "resolve_config",
    "to_jsonable",
]


class ValidationError(ValueError):
    pass


class HardwareError(RuntimeError):
    pass


class IKError(RuntimeError):
    pass


class IKTraceError(IKError):
    def __init__(self, message: str, *, details: Optional[Dict[str, Any]] = None):
        super().__init__(message)
        self.details = details or {}


@dataclass(frozen=True)
class SoArmMoceConfig:
    port: str
    robot_id: str
    calib_dir: Path
    urdf_path: Path
    target_frame: str
    home_joints: Dict[str, float]
    joint_scales: Dict[str, float]
    arm_p_coefficient: int
    arm_d_coefficient: int
    max_ee_pos_err_m: float
    linear_step_m: float
    joint_step_deg: float
    cartesian_settle_time_s: float
    cartesian_update_hz: float
    joint_update_hz: float
    ik_target_tol_m: float
    ik_max_iters: int
    ik_damping: float
    ik_step_scale: float
    ik_joint_step_deg: float
    ik_seed_bias: float


@dataclass(frozen=True)
class MultiTurnCalibration:
    home_wrapped_raw: int
    min_relative_raw: int
    max_relative_raw: int


def _env_value(*keys: str, default: str = "") -> str:
    for key in keys:
        raw = os.environ.get(key)
        if raw is None:
            continue
        value = str(raw).strip()
        if value:
            return value
    return default


def _load_calibration_payload(robot_name: str, calib_dir: Path) -> dict[str, dict[str, Any]]:
    fpath = calib_dir / f"{robot_name}.json"
    if not fpath.exists():
        raise FileNotFoundError(f"Calibration file not found: {fpath}")
    payload = json.loads(fpath.read_text(encoding="utf-8"))
    if not isinstance(payload, dict):
        raise ValidationError(f"Calibration file must contain a JSON object: {fpath}")
    return payload


def _build_bus_calibration(payload: dict[str, dict[str, Any]]) -> dict[str, MotorCalibration]:
    calibration: dict[str, MotorCalibration] = {}
    for joint_name, raw_entry in payload.items():
        if not isinstance(raw_entry, dict):
            raise ValidationError(f"Calibration entry for {joint_name} must be an object")
        calibration[joint_name] = MotorCalibration(
            id=int(raw_entry["id"]),
            drive_mode=int(raw_entry.get("drive_mode", 0)),
            homing_offset=int(raw_entry.get("homing_offset", 0)),
            range_min=int(raw_entry["range_min"]),
            range_max=int(raw_entry["range_max"]),
        )
    return calibration


def _load_calibration(robot_name: str, calib_dir: Path) -> dict[str, MotorCalibration]:
    return _build_bus_calibration(_load_calibration_payload(robot_name, calib_dir))


def _load_multi_turn_calibration(payload: dict[str, dict[str, Any]]) -> dict[str, MultiTurnCalibration]:
    calibration: dict[str, MultiTurnCalibration] = {}
    for joint_name in MULTI_TURN_JOINTS:
        raw_entry = payload.get(joint_name)
        if raw_entry is None:
            continue
        if not isinstance(raw_entry, dict):
            raise ValidationError(f"Calibration entry for {joint_name} must be an object")
        try:
            home_wrapped_raw = int(raw_entry["home_wrapped_raw"]) % int(RAW_COUNTS_PER_REV)
            min_relative_raw = int(raw_entry["min_relative_raw"])
            max_relative_raw = int(raw_entry["max_relative_raw"])
        except KeyError as exc:
            raise ValidationError(
                f"Multi-turn calibration for {joint_name} is missing required field: {exc.args[0]}"
            ) from exc
        if min_relative_raw >= max_relative_raw:
            raise ValidationError(
                f"Invalid multi-turn raw span for {joint_name}: min={min_relative_raw}, max={max_relative_raw}"
            )
        calibration[joint_name] = MultiTurnCalibration(
            home_wrapped_raw=home_wrapped_raw,
            min_relative_raw=min_relative_raw,
            max_relative_raw=max_relative_raw,
        )
    return calibration


def _candidate_calibration_dirs() -> list[Path]:
    env = _env_value("SOARMMOCE_CALIB_DIR")
    candidates: list[Path] = []
    if env:
        candidates.append(Path(env).expanduser())
    candidates.extend(
        [
            SKILL_ROOT / "calibration",
            Path.home() / ".cache/huggingface/lerobot/calibration/robots/so101_follower",
            REPO_ROOT / "Software/Slave/calibration/robots/so101_follower",
            REPO_ROOT / "Software/Master/calibration/robots/so101_follower",
            Path.cwd() / "Software/Slave/calibration/robots/so101_follower",
            Path.home() / "Code/SO-ARM-Moce/Software/Slave/calibration/robots/so101_follower",
        ]
    )
    unique: list[Path] = []
    seen: set[str] = set()
    for path in candidates:
        try:
            key = str(path.resolve()) if path.exists() else str(path)
        except Exception:
            key = str(path)
        if key in seen:
            continue
        seen.add(key)
        unique.append(path)
    return unique


def _candidate_calibration_robot_ids() -> list[str]:
    env_robot_id = _env_value("SOARMMOCE_ROBOT_ID")
    if env_robot_id:
        return [env_robot_id]
    candidates = ["soarmmoce", "follower_moce"]
    unique: list[str] = []
    seen: set[str] = set()
    for robot_id in candidates:
        key = str(robot_id).strip()
        if not key or key in seen:
            continue
        seen.add(key)
        unique.append(key)
    return unique
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

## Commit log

2026-02-19 feat: Add sdk
    [base.STL, elbow.STL, gripper.STL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]
2026-02-19 feat:add calibration
2026-02-19 feat: Add ultra lightweight arm server and utility functions
    - Implemented `main.py` for the ArmServer, enabling real-time control and smooth motion to target positions.
    - Integrated camera support with HardwareStreamer for video streaming.
    - Added socket communication for command handling and status updates.
    - Created `so101_utils.py` for loading motor calibration and setting up the motor bus.
    - Included functions for reading joint angles and configuring motors.
    [so101.urdf, soarmoce_urdf_resolved.urdf]
2026-02-19 feat: Add URDF file for robot model
    [urdf.xlsx]
2026-02-19 Add robot model and transport layer implementation
    - Introduced new STL mesh files for robot components: base, elbow, gripper, shoulder, shoulder_lift, wrist, and wrist_roll.
    - Created URDF file for the robot model, defining links, joints, and their properties.
    - Implemented transport layer with base class and mock transport for testing.
    - Added serial and TCP transport classes with placeholders for future implementation.
    - Developed unit tests for forward and inverse kinematics, joint limits, and mock transport functionality.
    - Removed outdated bytecode files from the repository.
    [base.STL, elbow.STL, gripper.STL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]
2026-02-19 feat: Remove obsolete tools for color block recognition and URDF visualization
2026-02-19 feat: Add script to display SOARM URDF in RViz2 and Gazebo
2026-02-19 feat: Add URDF data in Excel format for robot model documentation
    [urdf.xlsx]
2026-03-05 feat: Enhance tool dispatcher and HMI with new functions for gripper control, joint rotation, and object scanning
2026-03-05 Add initial implementation of SoarMoce SDK with transport layers and URDF configuration
    - Introduced transport layer with Mock, Serial, and TCP transports.
    - Added base transport interface for common functionality.
    - Implemented mock transport for testing without hardware.
    - Created SerialTransport as a placeholder for future implementation.
    - Developed TCPTransport for communication using JSON protocol.
    - Added URDF configuration for the SoarMoce robot model.
    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
    [Apple.CATPart, base.STL, elbow.STL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]
2026-03-08 feat: Enhance frame semantics and natural language mapping for robot control
2026-03-10 feat: Implement SoarmMoce control scripts and SDK
    - Updated OpenAI agent configuration to reflect new script names and class imports.
    - Added shared CLI helper functions in `soarmmoce_cli_common.py` for consistent command-line interface handling.
    - Created `soarmmoce_gripper.py` for gripper control commands, noting that gripper functionality is unsupported on current hardware.
    - Developed `soarmmoce_move.py` for arm motion commands, supporting various movement types (delta, absolute, joint, and home).
    - Introduced `soarmmoce_sdk.py` as the main SDK for controlling the SoarmMoce arm, including configuration loading and movement logic.
    - Added `soarmmoce_state.py` to read and print the current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
2026-03-12 feat: Enhance face detection and control logic with secondary tilt joint support
2026-03-12 feat: Add interactive manual calibration script for soarmMoce real arm
    - Implemented `soarmmoce_manual_calibrate.py` for manual calibration of joints.
    - Introduced `ManualCalibrateRobotConfig` and `ManualCalibrateConfig` data classes.
    - Added functions for capturing home poses, recording manual ranges, and applying selected calibration.
    - Integrated validation for home pose offsets and multi-turn joint handling.
    - Enhanced `soarmmoce_sdk.py` with multi-turn calibration support and runtime modes.
    - Created `soarmmoce_test_calibrated_limits.py` to exercise calibrated multi-turn joint limits with safety checks.
